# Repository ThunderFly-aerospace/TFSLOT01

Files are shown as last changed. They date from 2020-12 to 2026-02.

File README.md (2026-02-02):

# TFSLOT: Clogging-free airspeed sensor

TFSLOT is a state-of-the-art airspeed sensor designed specifically for use in Unmanned Aerial Vehicles (UAVs). Utilizing the principle of the [Venturi effect](https://en.wikipedia.org/wiki/Venturi_effect) with a differential pressure sensor for accurate airspeed measurement, this device is also equipped with an integrated [Inertial Measurement Unit](https://en.wikipedia.org/wiki/Inertial_measurement_unit) (IMU). The unique design and features of TFSLOT01 solve common issues associated with Pitot tubes, offering a robust solution for aerial applications.

<p align="center">
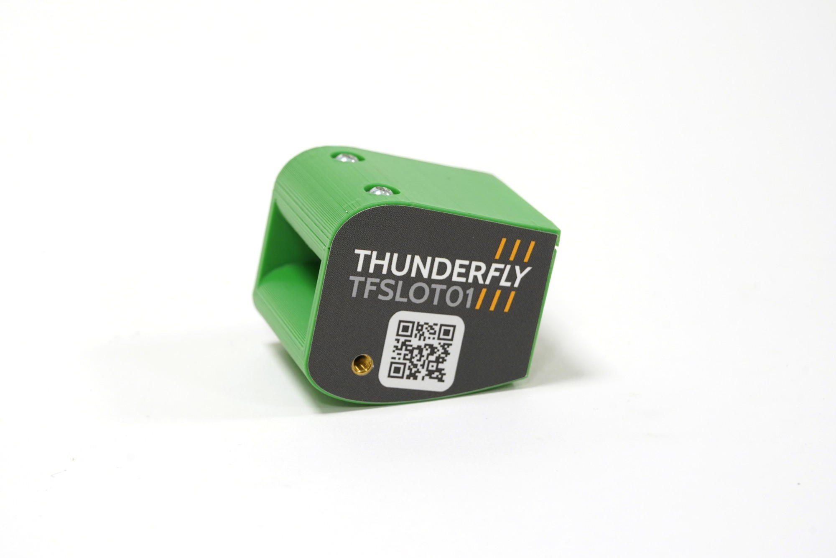
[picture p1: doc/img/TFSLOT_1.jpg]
  
</p>

## TFSLOT01 features
- **High Resolution** at low airspeeds (below 10 m/s)
- **Configurable Sensitivity** by modifying the airfoil profile
- **Reduced Susceptibility to Clogging**, for instance, by mud or snow upon landing
- **Weatherproof**, it can be used in various conditions
- **Direct Differential Pressure Sensor Integration** without the need for additional tubing
- **Possibility of Direct Integration** into the drone's mechanical structure
- **Open Design** making the design documentation accessible
- **Integrated IMU Unit** for measuring vibrations, angle of attack, and more

## How It Works?
The TFSLOT01 sensor uses the Venturi effect to measure airspeed, allowing precise tracking of airspeed even at low speeds.

<p align="center">
  
</p>

Air at a certain airspeed enters through an opening between two precisely defined airfoil profiles. As the depth within the sensor increases, the effective cross-section area decreases. Since the same volume of air must pass through a smaller cross-section, the flow velocity inside the sensor increases. As a result, based on the law of conservation of energy, the pressure decreases.

Inside the sensor, there are two sampling points connected to the differential pressure sensor by a channel. The measured pressure difference is then recalculated into the airspeed at the sensor's inlet. In addition to airspeed sensing, the sensor includes an integrated IMU unit that can also serve as an external magnetometer, because airspeed sensors are usually placed away from electromagnetic interference sources.

<p align="center">
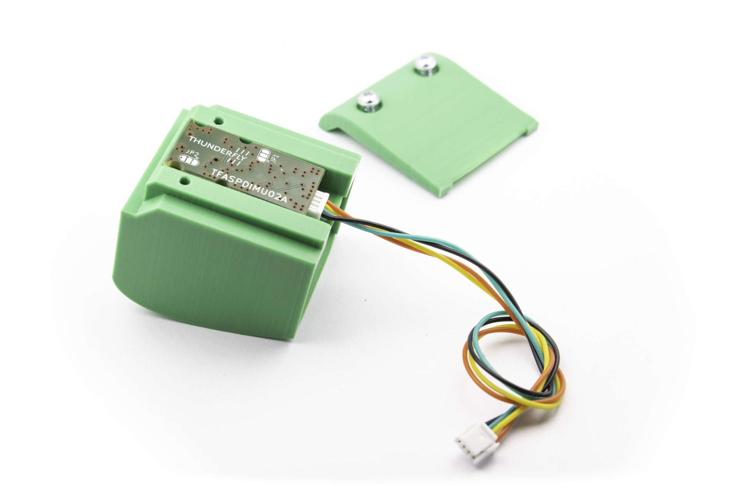
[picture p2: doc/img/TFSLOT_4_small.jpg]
  
</p>

## Where to get TFSLOT01?



TFSLOT can be bought directly from us via our contact [email](https://www.thunderfly.cz/contact-us.html). The email can also be used if there are specific requirements for custom modifications or if the product will be inquired in large quantities. TFSLOT is also available for online purchase through the [Tindie store](https://www.tindie.com/products/thunderfly/tfslot01a-airspeed-sensor-with-integrated-imu/).

## Support and Integration

### Drone avionics
The TFSLOT01A sensor (PCB board [TFASPDIMU02](https://github.com/ThunderFly-aerospace/TFASPDIMU02)) is currently supported by the PX4 autopilot, where it can be utilized both as an airspeed sensor and as an external IMU unit (external magnetometer). Instructions for integrating the sensor with the PX4 autopilot can be found in the official [PX4 documentation](http://docs.px4.io/master/en/sensor/airspeed.html#airspeed-sensors). The sensor is also hardware-compatible with other autopilots, such as Ardupilot, but currently lacks the computation code to convert differential pressure into airspeed.

### Robotics and measurement
For other applications, the sensor can be easily connected to any computer with an I2C interface, such as RaspberryPi or a generic desktop with a USB to I2C converter (e.g., [USBI2C02](https://www.mlab.cz/module/USBI2C01/), [shop it on tindie](https://www.tindie.com/products/mlab-project/mlab-usbi2c01a-usb-to-smbusi2c-bridge/)), and the differential pressure values or values from the IMU unit can be read, for example, by a Python script.

# FAQ
Frequently asked questions are listed on [TFSLOT's documentation page](https://docs.thunderfly.cz/avionics/TFSLOT01#faq)

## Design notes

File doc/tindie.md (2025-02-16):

## TFSLOT01: Clogging-Free Airspeed Sensor for UAVs

An innovative Venturi-effect airspeed sensor with a 9-axis IMU and customizable design. Open-source and ideal for low-speed UAVs.

---

The **TFSLOT01** is a next-generation airspeed sensor designed for UAVs. It uses the Venturi effect for superior performance at low airspeeds. This clog-resistant design is coupled with an integrated 9-axis IMU to be ready for additional diagnostic capabilities like vibration monitoring and angle-of-attack measurements.

This product is fully open-source, with a customizable 3D-printed case for seamless integration into UAV designs. Whether you're a developer, researcher, or enthusiast, the TFSLOT01 provides reliability, adaptability, and advanced functionality.

### Key Features

- **Clog-Resistant Design**: Venturi-based measurement removes stagnation point.
- **Integrated IMU**: Features a 9-axis IMU (magnetometer, accelerometer, gyroscope) for advanced diagnostics.
- **Customizable**: 3D-printed housing can be adapted to specific applications.
- **Weatherproof Build**: IP42-rated for reliable operation in diverse conditions.
- **Enhanced Resolution**: Optimized for speeds below 10 m/s.
- **Direct Integration**: No need for additional tubing, reducing maintenance concerns.

### Why Choose TFSLOT01?

The TFSLOT01 offers reliable airspeed measurement with its innovative Venturi-effect design, ensuring high accuracy and clog-free operation at low speeds. If you're looking for a lightweight and compact airspeed sensor based on the proven Pitot-static principle, check out our [TFPITOT01](https://www.tindie.com/products/37220/). Designed for minimal weight and precise measurements, it’s an excellent choice for applications where every gram matters.  

### Technical Specifications

| **Parameter** | **Value** | **Description** |
|---|---|---|
| Airspeed Range | 0 - 48 m/s | Assumes air density of 1.29 kg/m³ |
| Dimensions | 35 x 40 x 35 mm | Default 3D-printed case |
| Weight | 25 g | Compact and lightweight |
| Operating Temperature | −20°C to +40°C | Reliable in diverse weather |
| Input Voltage | +3.6V to +5.4V | Overvoltage protection included |
| I2C Connector | 4-pin JST-GH | Pixhawk-compatible standard |
| Weather Resistance | IP42 | Protection against dust and water splashes|

The sensor can operate at any altitude, but sensitivity decreases as air density drops. See the documentation for details.

### Compatibility

- **PX4 Autopilots**: Full airspeed and IMU integration.
- **Ardupilot**: Hardware-compatible (airspeed calculations require manual configuration).
- **Custom Systems**: Supports I2C interfaces.

Follow the [PX4 guide](https://docs.px4.io/main/en/sensor/airspeed_tfslot.html#tfslot-venturi-effect-airspeed-sensor) for setup.

### Included in the Package

- TFSLOT01 sensor (assembled and ready to use)
    - 3D-printed protective case
    - Sealing O-rings
    - Optional I2C cable

### Accessories

For enhanced reliability and flexibility, we offer high-quality [I2C cables](https://www.tindie.com/products/thunderfly/tfcab15i2c01-15-cm-i2c-cable-for-pixhawk-drones/), specially designed to minimize electromagnetic interference.

### Product Changelog

- **TFSLOT01C (2024)**: Enhanced mounting options for broader compatibility.
- **TFSLOT01B (2022)**: Upgraded electronics for better performance.
- **TFSLOT01A (2021)**: Initial prototype (not publicly released).

For full details, visit the [releases](https://github.com/ThunderFly-aerospace/TFSLOT01/releases).

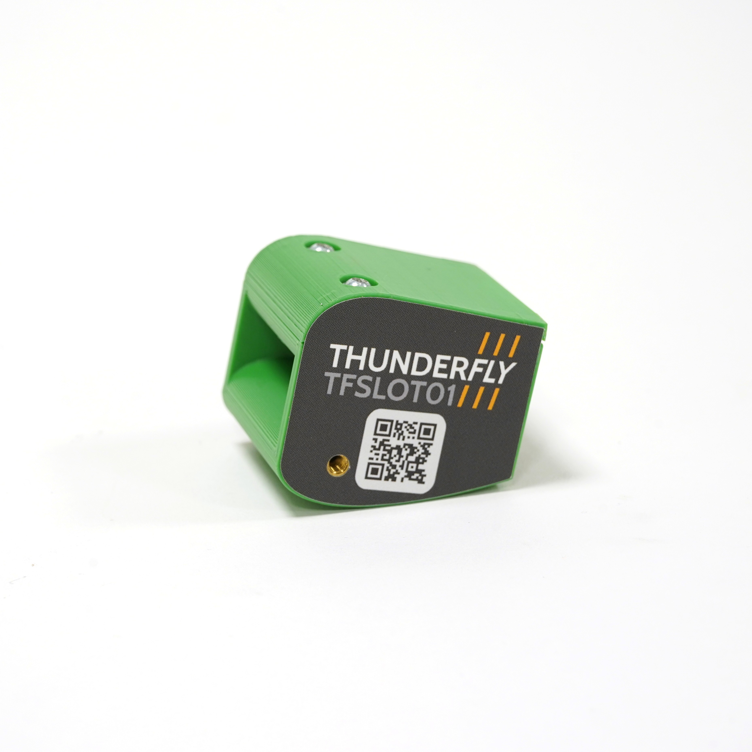
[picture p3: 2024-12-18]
doc/img/ThunderFly_TFSLOT01.jpg

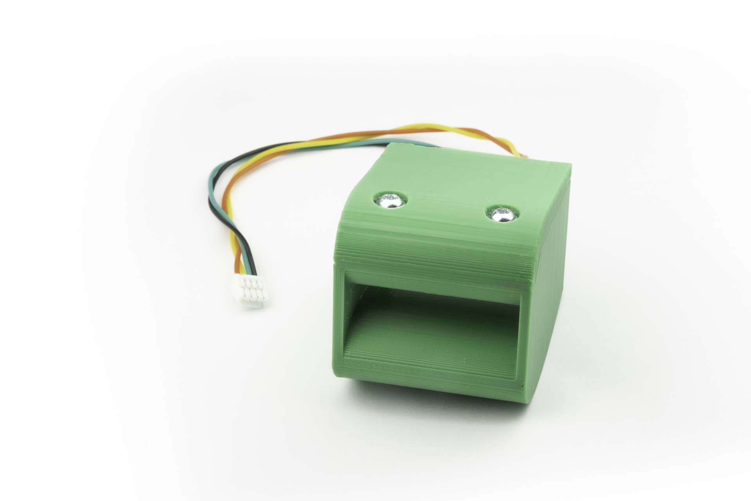
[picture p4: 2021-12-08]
doc/img/TFSLOT_1_small.jpg

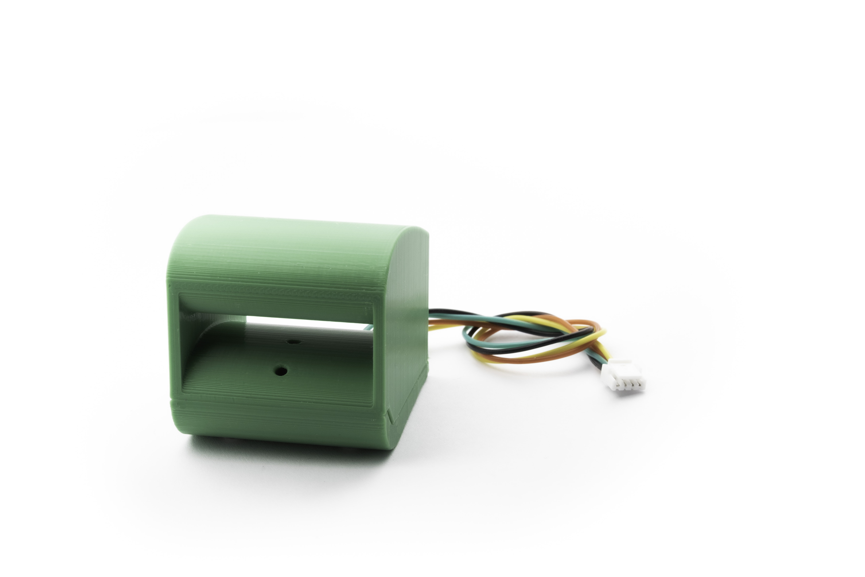
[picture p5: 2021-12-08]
doc/img/TFSLOT_2.jpg

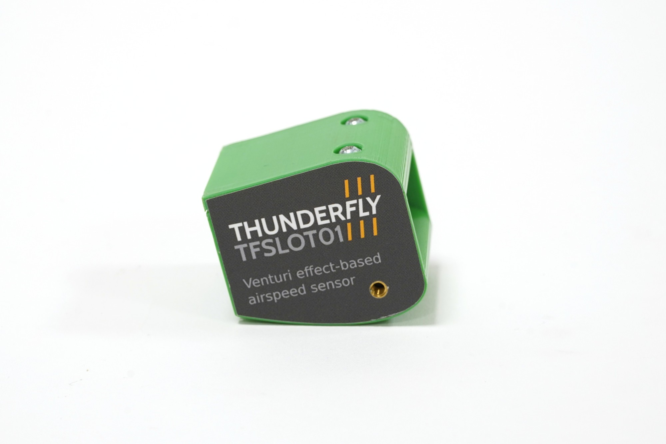
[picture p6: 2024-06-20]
doc/img/TFSLOT_3.jpg

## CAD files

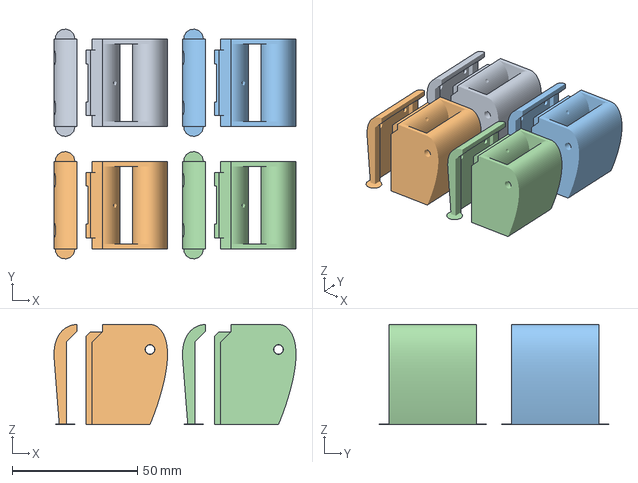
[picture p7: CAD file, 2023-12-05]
CAD/slicing/TFSLOT_complete.3mf
96.8 x 91.9 x 40.0 mm

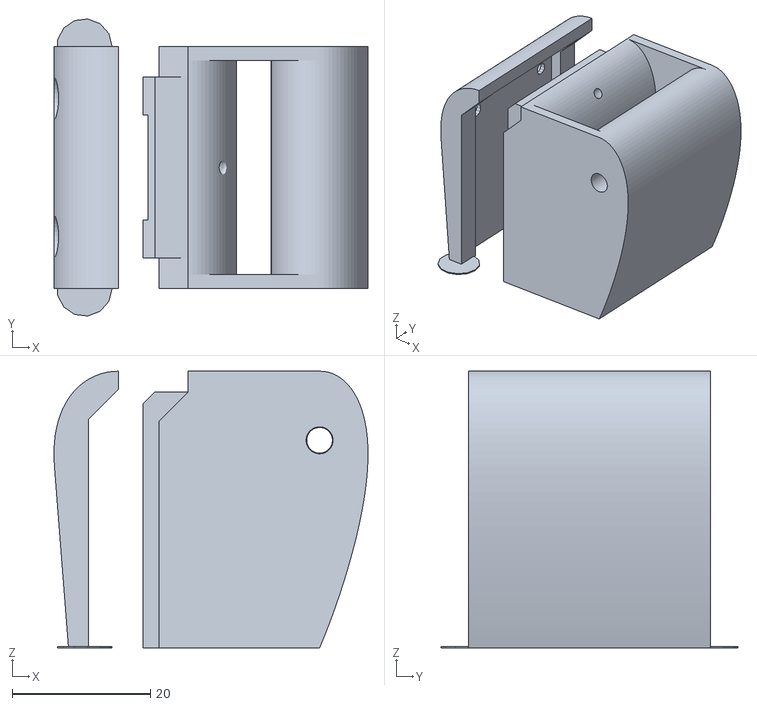
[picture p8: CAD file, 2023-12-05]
CAD/src/stl/tfslot_complete.stl
45.4 x 42.9 x 40.0

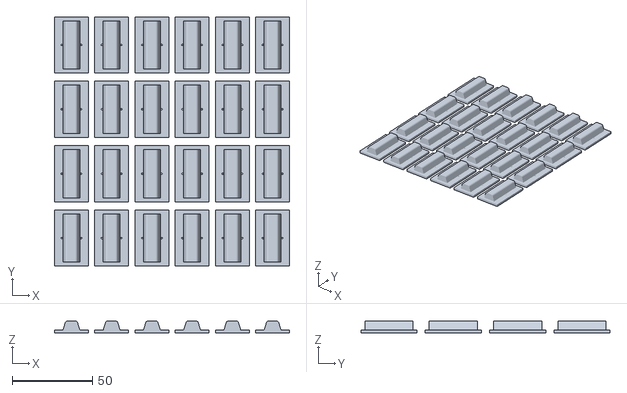
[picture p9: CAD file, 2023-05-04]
CAD/src/stl/tfslot_888_1003_multiple.stl
146.0 x 155.0 x 7.50

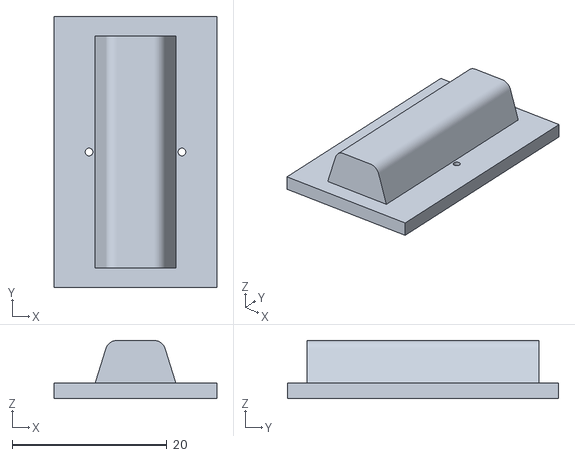
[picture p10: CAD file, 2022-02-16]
CAD/src/stl/tfslot_888_1003.stl
21.0 x 35.0 x 7.50

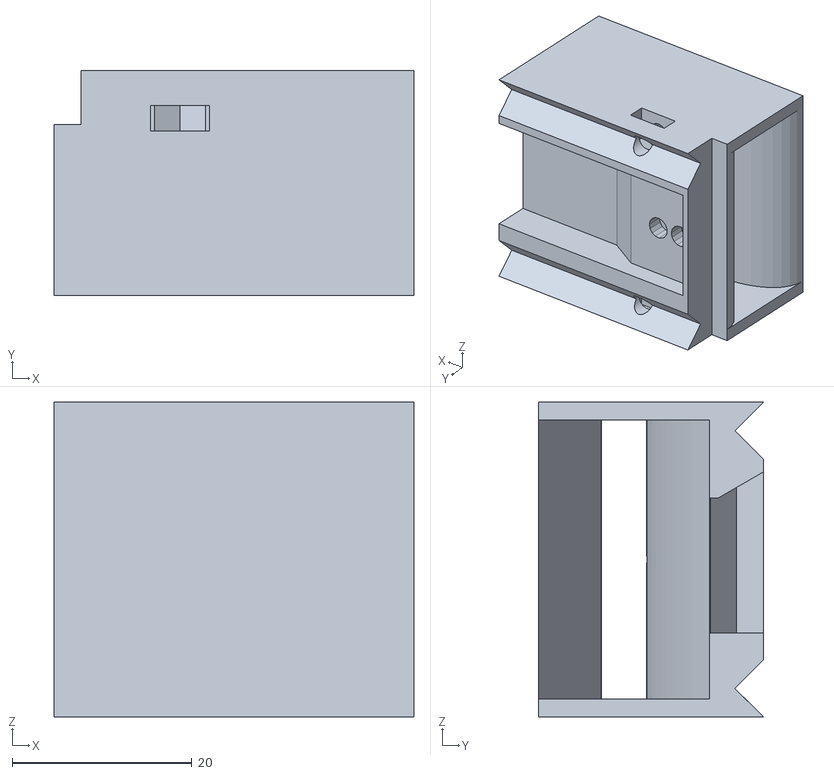
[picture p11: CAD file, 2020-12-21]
CAD/src/stl/printplate_tfslot_888_1001.stl
40.0 x 25.0 x 35.0

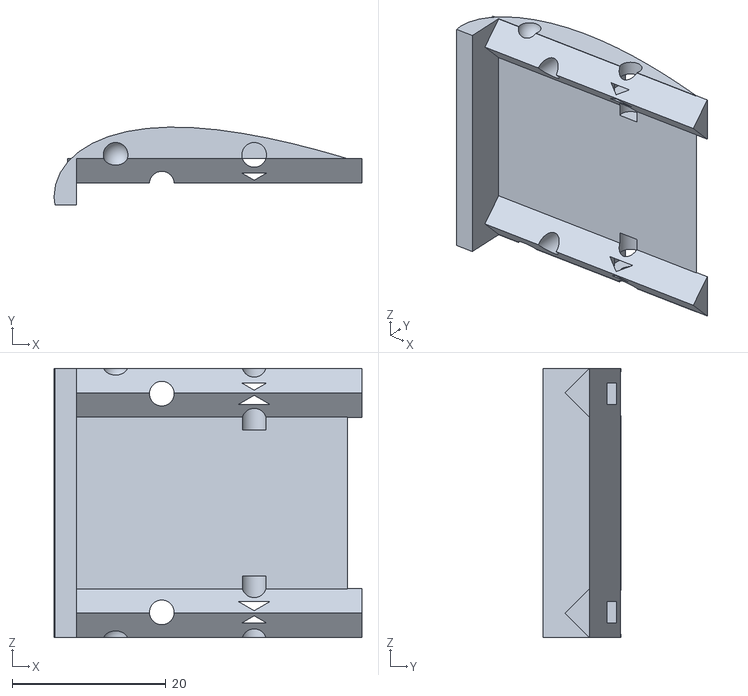
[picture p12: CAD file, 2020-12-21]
CAD/src/stl/printplate_tfslot_888_1002.stl
40.0 x 10.1 x 35.0

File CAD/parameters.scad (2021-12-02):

global_clearance = 0.1;

//Screw diameter and nut for M3 [mm]
M3_screw_diameter = 3.2;
M3_nut_height = 2.7;
M3_nut_diameter = 6.6;
M3_screw_head_height = 3;
M3_nut_pocket = 5.6;
M3_head_diameter = 6.6;
M3_head_height = 3.0;

PLASTFAST_diameter = 2.3;
PLASTFAST_head_diameter = 6;

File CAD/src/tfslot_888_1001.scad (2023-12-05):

include <../parameters.scad>

global_clearance = 0.1;

use <lib/stdlib/curvedPipe/curvedPipe.scad>
use <lib/stdlib/naca4.scad>
use <lib/stdlib/bolts.scad>

$fn = 200;

type = "naca"; // "naca" or "cylinder"
//type = "cylinder";
width = 35;

pipe_d = 2;

// for NACA type
naca = 0035;
distance = 19;
length = 40;
profile_thickness = surface_distance(x = 0.25, naca = naca)*length;

sensor_rantl = 3;
sensor_pos = [9.5, distance/2 + sensor_rantl, width/2];
sensor_nose_distance = 4.3;
sensor_nose_hole_depth = 2.5;
sensor_nose_hole_diameter = 3.5;
sensor_sealing_nose_diameter = 1.5;
sensor_sealing_nose_length = 2;



M3_screw_diameter = 3.3;
M3_insert_hole = 3.9;


// Krabicka na PCB

pcb_width = 15.2;
pcb_offset = 0;
pcb_length = 36;
pcb_sensor_from_top = 5;
pcb_thickness = 3.5;
pcb_thickness_sensor = 3.4;
pcb_thickness_conn = 6;

pipe1_pos = [type=="naca"? 3: stage1_len/2, 0, width/2];
pipe2_pos = [type=="naca"?length*0.3 : stage2_pos+stage2_len/2, 0, width/2];

// PCB cap
cap_head_overlay = 3;
rail_x = 4.5;
rail_h = rail_x/2-0.1;
bolt_size = 3;
bolt_len = 10;
bolt_z = 15 - head_height(bolt_size); // top of cap - head_height


mounting_thread = 1;



module pipes()
{
    // Cabling
    //mid_body_horizontal = (R03_wide_D/2 + R03_narrow_D/2) / 2;
    //mid_body_vertical = wide_body_length + exhaust_length + R03_narrow_D/2;
    //PCB_y = -R03_wide_D/2 - R03_wall_thickness - R03_PCB_elevation;
    //PCB_z = R03_venturi_tube_height - R03_PCB_height*1.1 - 5;
    //pipe_elevation = PCB_z - slip_ring_z;
    //d = (R03_wide_D + 2*R03_wall_thickness)/2 - R03_narrow_D/2 - R03_wall_thickness;
    //cbl_x = 0;

width = 30;
distance = 50;

h = width/2;
d = 3;

echo("NACA");
 th = surface_distance(x = 0.25, naca = naca)*60;
 echo(th);
 cube(50/2-th);

curvedPipe([[10, distance/2, h],
            [100,0, h],
            [100,100, h],
            [100, 100, h],
            [100, 00, h]
		   ],
            4,
			[10, 10, 20, 20],
		    d, 0);

}
//pipes();


//  Hlavni cast TFSLOTU
//
//  width_param = sirka sterbiny TFSLOTU
//  one_part = ... tohle je nejaky historicky pozustatek? Ale aktualne to zapina drazku na vicko
// plastfast_screw = Vicko pripevnit samoreznym sroubem; hodnota je vzdalenost od sebe
// cap_hole = tohle je zarez na vicko, zkoseni hran. Odebrani nabezne hrany

module tfslot_888_1001(width_param = width, one_part=false, plastfast_screw = 0, cap_hole = 0){

width = width_param;

translate([0, -width/2, 0]) rotate([-90, 0, 0]) difference(){


// Horni profil
    union(){
        
        translate([length-2, -distance/2, 0]) cube([2, 0.15, width]);
        translate([length-20, distance/2, 0]) cube([20, 0.4, width]);
        
        translate([0, -distance/2, 0])
            airfoil(naca = naca, L = length, N = 100, h= width, open = false);
        
        intersection(){
            translate([0, -distance/2, 0])
                airfoil(naca = 0015, L = length, N = 100, h= width, open = false);
            translate([0,-distance/2, 0])
                cube([length, distance, width]);
        }
        
// Bocni steny
        translate([0, -distance/2, 0])
            cube([length, distance, 2]);
        translate([0, -distance/2, width-2])
            cube([length, distance, 2]);

    // Spodni profil (profil se senzorem)
    difference(){
        union(){
            intersection(){
                hull(){
                    translate([0, distance/2, 0])
                        airfoil(naca = naca, L = length, N = 100, h= width, open = false);
                    translate([0, distance/2+3, 0])
                        airfoil(naca = naca, L = length, N = 100, h= width, open = false);
                }
                union(){
                    translate([0, -distance/2, 0])
                        cube([length, distance, width]);
                    translate()
                        cube([3, distance-3, width]);
                }
            }

            // schod pro PCB
            hull(){
                translate([-15/2 + sensor_pos[0], distance/2, 0])
                    cube([15, sensor_rantl, width]);
                translate([-15/2 + sensor_pos[0], distance/2-0.1, 0])
                    cube([25, 0.1, width]);
            }

            // Krabicka na PCB
            union(){
                translate([sensor_pos[0] - pcb_sensor_from_top - 0.5, distance/2, 0])
                    cube([pcb_length, sensor_rantl + pcb_thickness,
                          width/2 - pcb_width/2 - pcb_offset]);
                translate([sensor_pos[0] - pcb_sensor_from_top - 0.5, distance/2,
                           width/2 + pcb_width/2 - pcb_offset])
                    cube([pcb_length, sensor_rantl + pcb_thickness,
                              width/2 - pcb_width/2 + pcb_offset]);
                translate([sensor_pos[0] - pcb_sensor_from_top - 2.5, distance/2, 0])
                    cube([2, sensor_rantl + pcb_thickness, width]);
            }
        }

        h = width/2;

        // trubicky pro tlak
        union(){
            if(!$preview)
            curvedPipe([
                    sensor_pos + [sensor_nose_distance/2,
                                  -sensor_nose_hole_depth-sensor_sealing_nose_length+0.1, 0],
                    sensor_pos + [sensor_nose_distance/2, -5, 0],
        			pipe2_pos  + [0, distance/2-6, 0],
        			pipe2_pos + [0, 0, 0]
                ],
                3,
    			[4, 4, 2, 2],
    		    pipe_d, 0
            );

            if(!$preview)
            curvedPipe([
                    sensor_pos + [-sensor_nose_distance/2,
                                  -sensor_nose_hole_depth-sensor_sealing_nose_length+0.1, 0],
                    sensor_pos + [-sensor_nose_distance/2, -7, 0],
        			pipe1_pos + [0, distance/2-4, 0],
        			pipe1_pos + [0, 0, 0],

                ],
                3,
    			[3, 2, 1, 2],
    		    pipe_d, 0
            );
            
            // Vyusteni trubicky do PCB
            for(x = [0.5, -0.5])
            translate(sensor_pos + [sensor_nose_distance*x, 0, 0])
                rotate([90, 0, 0]){
                    cylinder(d = sensor_nose_hole_diameter, h= sensor_nose_hole_depth,
                             center=true, $fn = 15);
                    translate([0, 0, sensor_nose_hole_depth/2-.01])
                        cylinder(d2 = sensor_sealing_nose_diameter, d1 = sensor_nose_hole_diameter,
                                 h= sensor_nose_hole_depth/2, $fn = 15);
                    translate([0, 0, sensor_nose_hole_depth])
                        cylinder(d2 = pipe_d, d1 = sensor_sealing_nose_diameter,
                                 h= sensor_sealing_nose_length, $fn = 15);
                }

            }
        }
    }
    
    
    if(plastfast_screw){
        translate([length/4, distance/2-5, width/2-plastfast_screw/2])
            rotate([-90, 0, 0])
                cylinder(d=PLASTFAST_diameter, h=30, $fn=14);
        translate([length/4, distance/2-5, width/2+plastfast_screw/2])
            rotate([-90, 0, 0])
                cylinder(d=PLASTFAST_diameter, h=30, $fn=14);
    }
    
    
    
    // Srouby pro zavitovou volozku
    if(mounting_thread){    
        translate([length/4, -distance/2, width/2-plastfast_screw/2]){
                
                cylinder(d=M3_screw_diameter+0.4, h=100, $fn=50, center=true);
                translate([0, 0, width/2+10-6]) cylinder(d=M3_insert_hole, h=100, $fn=50);
                translate([0, 0, -width/2-90+6]) cylinder(d=M3_insert_hole, h=100, $fn=50);

        }
    }

    
    if(cap_hole) {
        union(){
            // Rails
            for(y = [rail_h, width - rail_h])
                translate([length/2 + 0.01, distance/2 + sensor_rantl + pcb_thickness , y])
                    cube([length, rail_x, rail_x], center=true);
            
            for(y = [rail_h, width - rail_h])
                translate([3, distance/2 , y - rail_x/2])
                    rotate([0, 0, 45]) cube([10, rail_x, rail_x]);
            
            translate([0, distance/2 + sensor_rantl + 2, width/2])
                rotate([0, 0, 45]) cube([10, rail_x, width], center=true);
                    
            // Lid front cut-out
            translate([0, distance/2 + sensor_rantl - 3, -0.01])
                cube([cap_head_overlay + 0.01, sensor_rantl + pcb_thickness + 0.01, width + 0.02]);
        }
    }
    }
}

tfslot_888_1001(one_part=true, plastfast_screw = 20, cap_hole = 1);
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

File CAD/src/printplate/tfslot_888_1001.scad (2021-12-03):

//@set_slicing_config(../../slicing/default.ini)
use<../tfslot_888_1001.scad>

translate([0, 0, 40]) rotate([0, 90, 0]) tfslot_888_1001(one_part=true, plastfast_screw = 20, cap_hole = 1);

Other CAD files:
CAD/src/printplate/tfslot_888_1002.scad
CAD/src/printplate/tfslot_888_1003.scad
CAD/src/printplate/tfslot_888_1003_multiple.scad
CAD/src/printplate/tfslot_complete.scad
CAD/src/printplate/tfslot_complete_6pcs.scad
CAD/src/printplate/tfslot_crossection.scad

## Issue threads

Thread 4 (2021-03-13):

Vytvořit referenční porovnání vůči pitot tube za nízkých rychlostí

kaklik, 2021-03-13:
Testovací měření by bylo potřeba zpracovat do podoby, kdy vznikne exakní srovnání vůči pitotce. Následně by se tím mělo reagovat na diskusi probíhající zde: https://discuss.px4.io/t/rpm-to-airspeed-sensor/21362

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

Předpokladem je dokončení issue #1

roman-dvorak, 2023-01-03:
Senzor prezentujeme jako senzor, který je schoný měřit velmi nízké airspeed s dobrou precission. Takové měření se zřejmě nedá provést ve venkovním prostředí, kde neustále existuje nějaké proudění vzduchu. Vznikly dva nápady, jak toto zrealizovat.

#### Minimalistický způsob měření
- Jednodichý na sestavení
- Těžko pravidelně opakovatelný.

TFSLOT, pitotku a jiný komereční senzor proudění umístit na vozíček, který se bude tahat skrze dlouhou chodbu, kde není žádné proudění vzduchu. Na vozíček by se postavil notebook a TFSLOT s pitotkou by se tam nějakým způsobem provizorně postavil. Vozíček by následně bylo možné buď strčit a sledovat, jak se mění měření a nebo s pomocí HBstepu a krokového motoru vybaveného kladkou vozíček tahat. Tak, aby jen konstantní rychlostí.

Představovaný (minimální) vozíček by vypadal nějak takto:
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

#### Vlastní minimalistický větrný tunel.

Navrhnout malý větrný tunel založený na ventilátoru a voštinové mřížce. Takový tunel by byl zřejmě jen pro tento účel.  Výhodou je, že měření zde lze velmi snadno opakovat a jsou zajištěny jednotné podmínky. Aktuálně neznáme vhodný existující model, který by takovou věc podporoval. Bylo by potřeba ho navrhnout a vytisknout.

Při drobné modifikaci by do tunelu bylo možné strčit celý pylonu TF-G2 s TFSLOTEM a sledovat chování proudění okolo pylonu a měření TFSLOTu přímo na místě pylonu.

#### Pokusit se domluvit měření na profesionálním tunelu

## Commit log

2020-09-25 Prvni verze airspeed policky
    [888_5001.scad]
2020-09-25 Druha verze airspeed policky
    [888_5001.scad]
2020-10-01 Uprava podle windguage
    [888_5001.scad]
2020-10-01 Uprava podle windguage, naca
    [888_5001.scad]
2020-10-02 nova verze airspeed
    [888_5001.scad]
2020-10-02 mensi verze
    [888_5001.scad]
2020-10-28 Uprava airspeed, priprava na vicko, ramecek okolo pcb
    [888_5001.scad]
2020-10-29 Rozmerova verze 2
    [888_5001.scad]
2020-12-03 ThunderFly-aerospace/TF-G2#16 Modifying PCB lid in 888_5001.scad to be aerodynamic. Work in progress.
    [888_5001.scad]
2020-12-03 pridani nutnych parametru
    [parameters.scad, tfslot_888_1001.scad]
2020-12-09 ThunderFly-aerospace/TF-G2#16 horizontal bolt cut-outs in cap, spherical cut-outs in cap and some cleaning-up.
    [tfslot_888_1001.scad]
2020-12-21 aktualizace submodulu, printplate, uprava parametru
    [tfslot_888_1001.scad, tfslot_888_1002.scad]
2021-02-03 modifikace pro TF-G2
    [tfslot_888_1001.scad]
2021-05-14 add width parameter
    [tfslot_888_1001.scad]
2021-05-16 TFSLOT full profile
    [tfslot_888_1001.scad]
2021-06-19 Spatne umisteni trubicek v TFSLOTu proti TFASPDIMU
    [tfslot_888_1001.scad]
2021-08-18 changed to fit TFASPDIMU02
    [tfslot_888_1001.scad]
2021-08-18 Added if for TF-G2 head
    [tfslot_888_1001.scad]
2021-09-22 Added bolts option
    [tfslot_888_1001.scad]
2021-09-22 Bolts option for 888_1002 fix
    [tfslot_888_1001.scad]
2021-12-02 uprava modelu
    [parameters.scad, tfslot_888_1001.scad, tfslot_888_1002.scad]
2021-12-03 Automatic commit from workflow
    [TF-MOTORSCALE_tfslot_888_1001.json, TF-MOTORSCALE_tfslot_888_1002.json, tfslot_888_1001.amf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]
2021-12-03 clean line
    [tfslot_888_1001.scad]
2021-12-03 clean repo, add submodule
    [TF-MOTORSCALE_tfslot_888_1001.json, TF-MOTORSCALE_tfslot_888_1002.json, tfslot_888_1001.amf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]
2021-12-03 update slicing profile
    [tfslot_888_1001.scad, tfslot_888_1002.scad]
2021-12-03 upravy printplate
    [tfslot_888_1001.scad]
2021-12-03 add support
    [tfslot_888_1001.scad, tfslot_888_1002.scad]
2021-12-03 cely printplate
    [tfslot_complete.scad]
2021-12-03 vylepseni tisknutelnosti vicka
    [tfslot_888_1001.scad, tfslot_complete.scad]
2021-12-07 uprava nahledu podlozky
    [tfslot_888_1001.amf, tfslot_888_1002.amf, tfslot_complete.amf]
2022-02-16 kalibracni pripravek
    [tfslot_888_1001.scad]
2022-02-16 add stl
    [tfslot_888_1003.scad, tfslot_888_1003.stl]
2022-02-16 printplate, amf soubory
    [tfslot_888_1001.scad, tfslot_complete_6pcs.scad]
2022-02-19 Update the readme and "calibration" procedure
2023-01-04 Explain higher sensitivity than pitot-static tube.
2023-05-04 add printplate for cap
    [tfslot_888_1003.scad]
2023-05-04 add multiple caps gcode
    [tfslot_888_1003_multiple.scad, tfslot_888_1003_multiple.stl]
2023-08-03 add screw hole
    [tfslot_888_1001.scad]
2023-08-08 thread insert
    [TFSLOT_complete.3mf, tfslot_complete.stl, tfslot_crossection.scad]
2023-12-05 new slicing
    [TFSLOT_complete.3mf]
2023-12-05 uprava profilu pro nove zavitove vlozky
    [TFSLOT_complete.3mf, tfslot_888_1001.scad, tfslot_complete.stl]
